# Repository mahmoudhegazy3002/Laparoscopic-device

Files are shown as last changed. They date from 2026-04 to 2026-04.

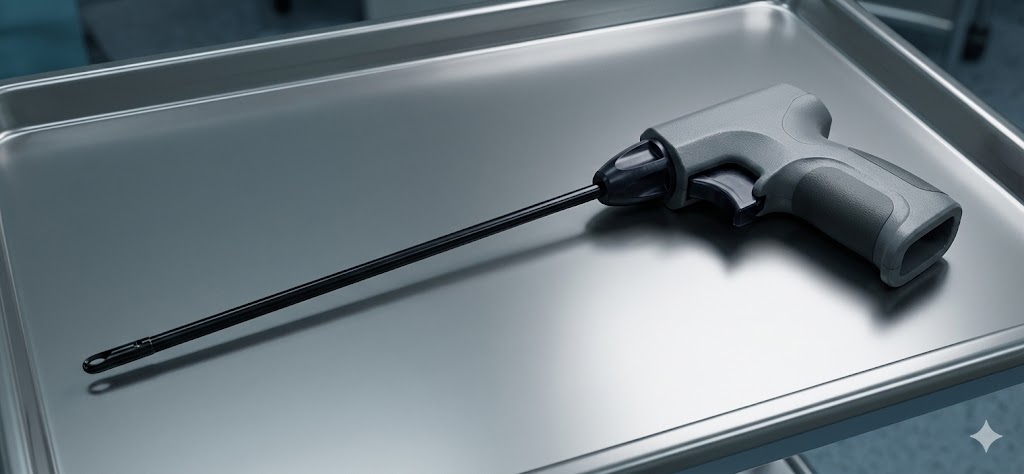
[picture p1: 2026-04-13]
sketches & ideas/unnamed.jpg

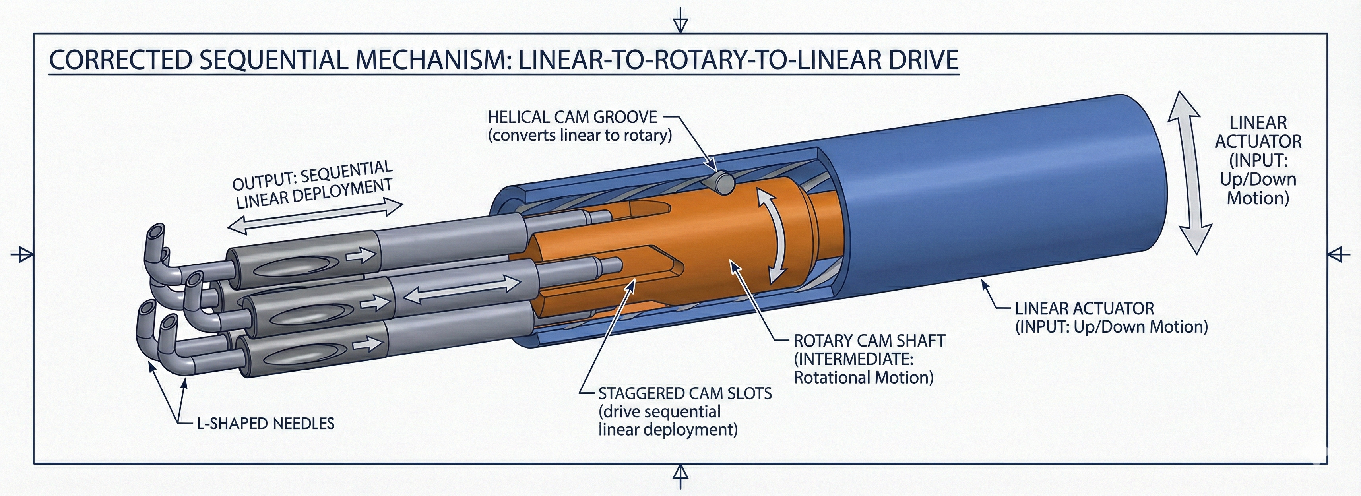
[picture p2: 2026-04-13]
sketches & ideas/img.jpg

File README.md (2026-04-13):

Laparoscopic Device: Kinematics & Force Simulation 🏥⚙️
📌 Project Overview

This project details the mechanical design and dynamic simulation of a specialized laparoscopic surgical tool. The primary engineering objective was to design a reliable mechanical actuation system and accurately model the resistance and force response of the tool's internal mechanisms during operation.
🛠️ Mechanical Design & Mechanisms

The device utilizes precision mechanisms to translate user input into accurate end-effector actuation.

    Native CAD: Designed parametrically in SolidWorks. The repository includes native .SLDPRT and universally accessible .STEP files.

    Cam Barrel Mechanism: Engineered to convert rotary/linear input into specific stroke lengths required for surgical precision.

    Trigger Release Technique: Designed a mechanical release system that ensures consistent actuation and safe reset functionality.

🧮 Dynamic Simulation & Force Modeling

A major component of this project was validating mechanical forces before physical prototyping. The entire kinematic chain was modeled and analyzed using MATLAB & Simscape Multibody.

    Resistance Simulation: Modeled the mechanical resistance of the trigger mechanism to ensure ergonomic operation.

    Mechanical Modeling: The simulation accounts for spring rates, dampening, and the mechanical advantage generated by the cam profile geometry.

📂 Repository Structure

    /cad — Contains SolidWorks feature tree files (.SLDPRT, .SLDASM) and .STEP files.

    /sim — Contains MATLAB/Simscape Multibody files (.slx) and initialization scripts.

    /docs — Contains mechanism diagrams and mathematical derivations for the cam profile.

🚀 How to Explore this Project

    CAD Review: Open the .STEP files in any standard CAD package or use SolidWorks to view the native feature trees.

    Simulation: To run the dynamic simulation, open the .slx file in MATLAB and execute the setup script to load the mechanical parameters.

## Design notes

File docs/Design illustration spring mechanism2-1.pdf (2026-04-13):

## Design and Dynamic Analysis of a Spring-Loaded Trigger Mechanism

Mechanism Engineering Report

March 14, 2026

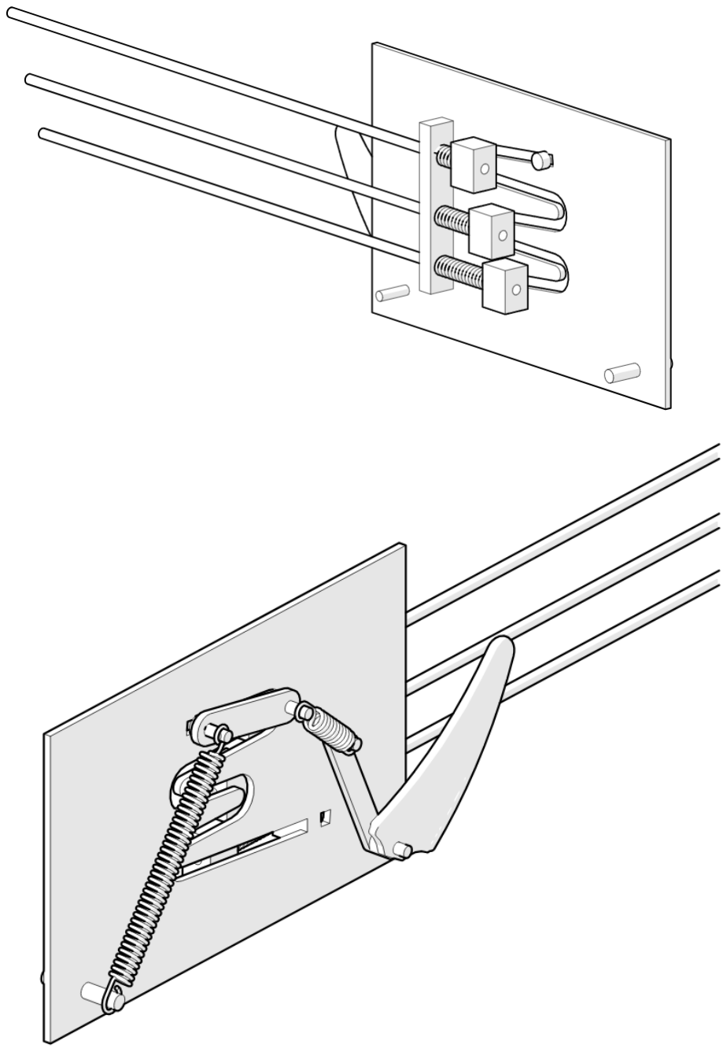
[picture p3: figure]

Abstract
This document details the design, kinematics, and dynamic simulation of a mechanical trigger assembly. The analysis includes a breakdown of the sub-components, an overview of the working principles, and an evaluation of the torque required to actuate the mechanism under a 0.5 kg load based on Simscape Multibody simulations.

## 1 Working Mechanism Illustration

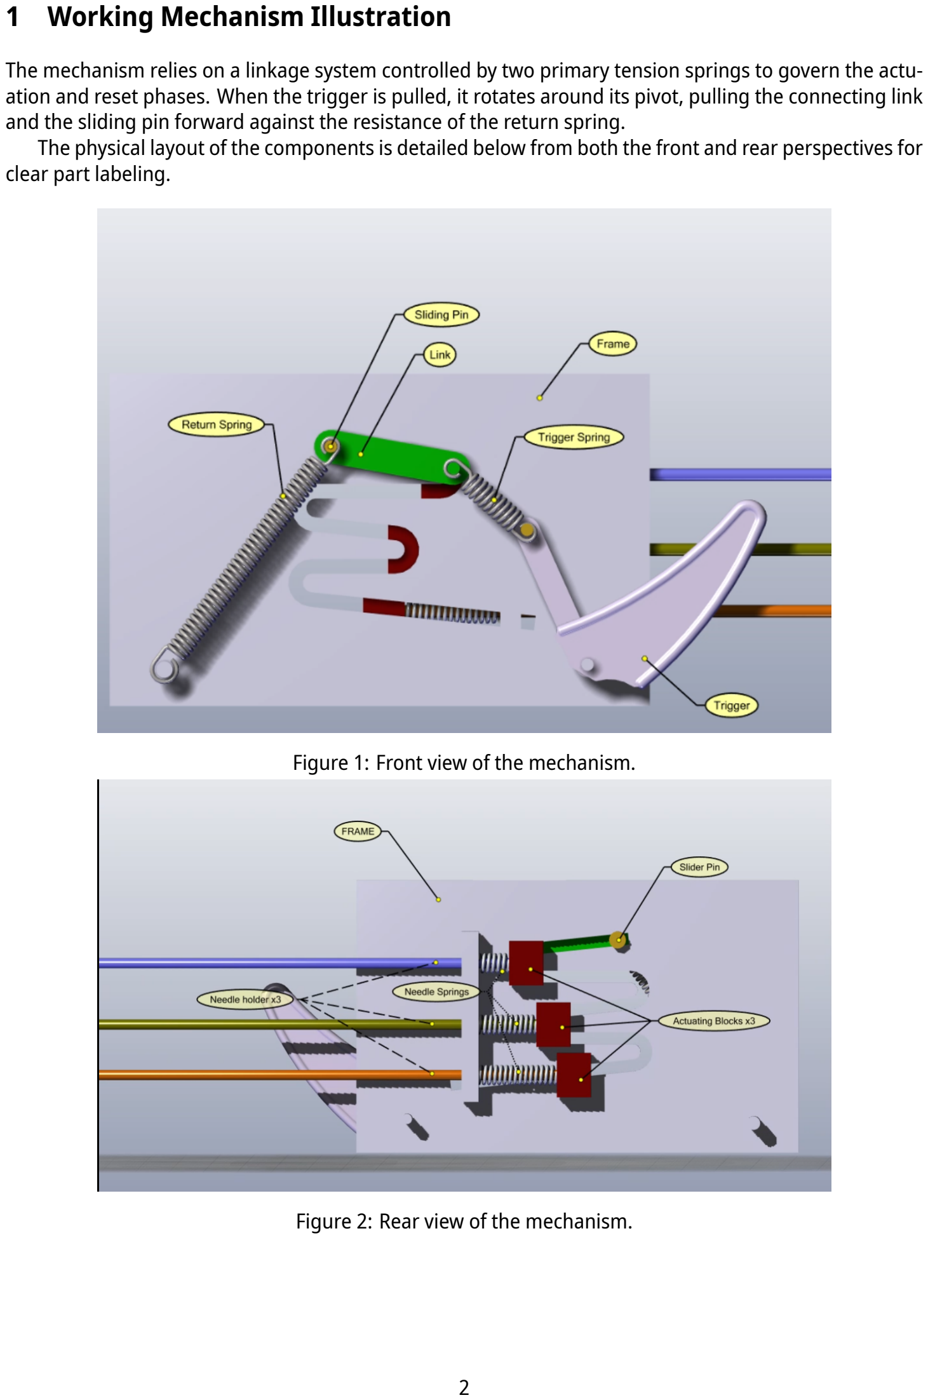
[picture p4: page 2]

The mechanism relies on a linkage system controlled by two primary tension springs to govern the actuation and reset phases. When the trigger is pulled, it rotates around its pivot, pulling the connecting link and the sliding pin forward against the resistance of the return spring.
The physical layout of the components is detailed below from both the front and rear perspectives for clear part labeling.

Figure 1: Front view of the mechanism.

Figure 2: Rear view of the mechanism.

The trigger spring maintains tension between the frame and the trigger to provide a crisp reset, while the heavier return spring is responsible for driving the sliding pin back to its resting state once the sear/trigger is released.

## 2 Parts List and Bill of Materials

The mechanism consists of a simplified kinematic chain with rigid bodies and force elements. The primary components are detailed in Table 1.

Table 1: Primary Components of the Trigger Assembly

Item No. Part Description | Quantity
1 | Frame | 1
2 | Trigger | 1
3 | Link | 1
4 | Sliding Pin (Slider Pin) | 1
5 | Trigger Spring | 1
6 | Return Spring | 1
7 | Needle Holder | 3
8 | Needle Spring | 3
9 | Actuating Block | 3
10 | Pivot Pins | 3

## 3 Operational Phases

The actuation cycle of the mechanism is broken down into six distinct phases, illustrating the progression of the linkages throughout a complete pull and reset cycle.

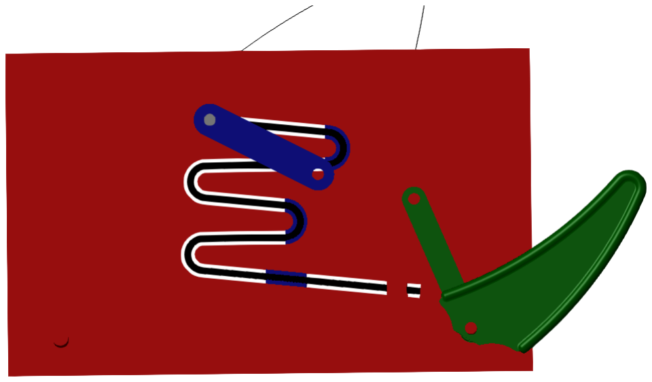
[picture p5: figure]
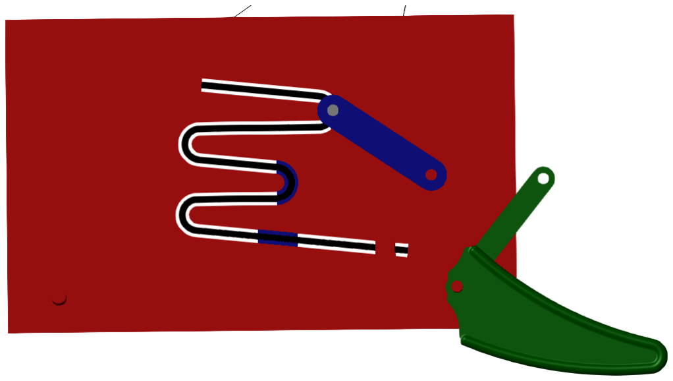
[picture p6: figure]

Figure 3: Phase 1: Initial Resting state. | Figure 4: Phase 2: pull and 1st needle actuated.

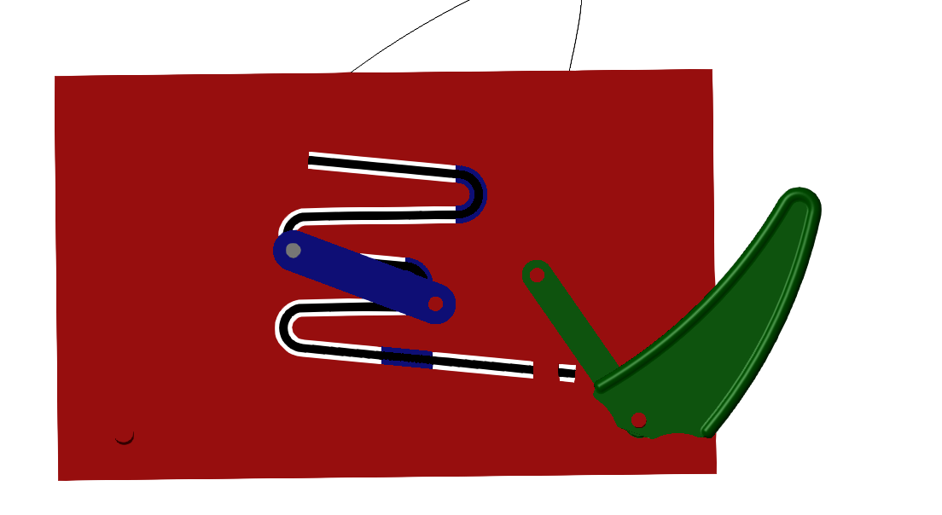
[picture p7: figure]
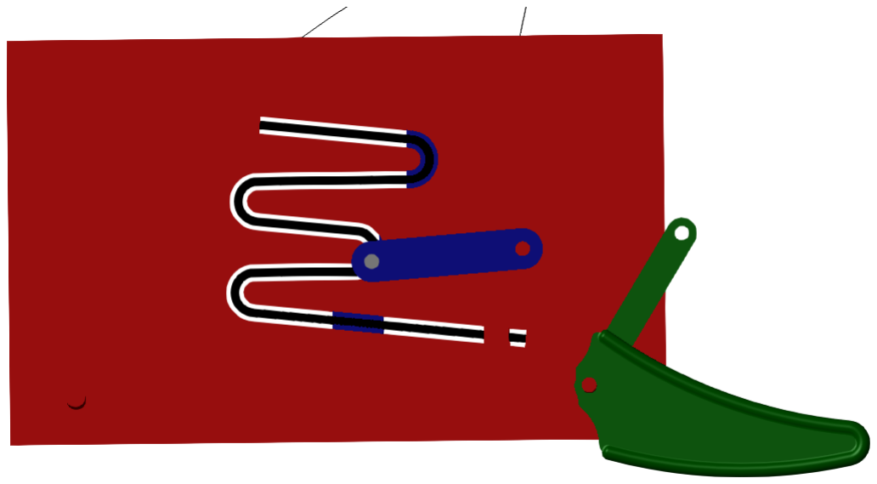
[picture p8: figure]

Figure 5: Phase 3: Release and 2rd resting state. Figure 6: Phase 4: Pull and 2nd needle actuated.

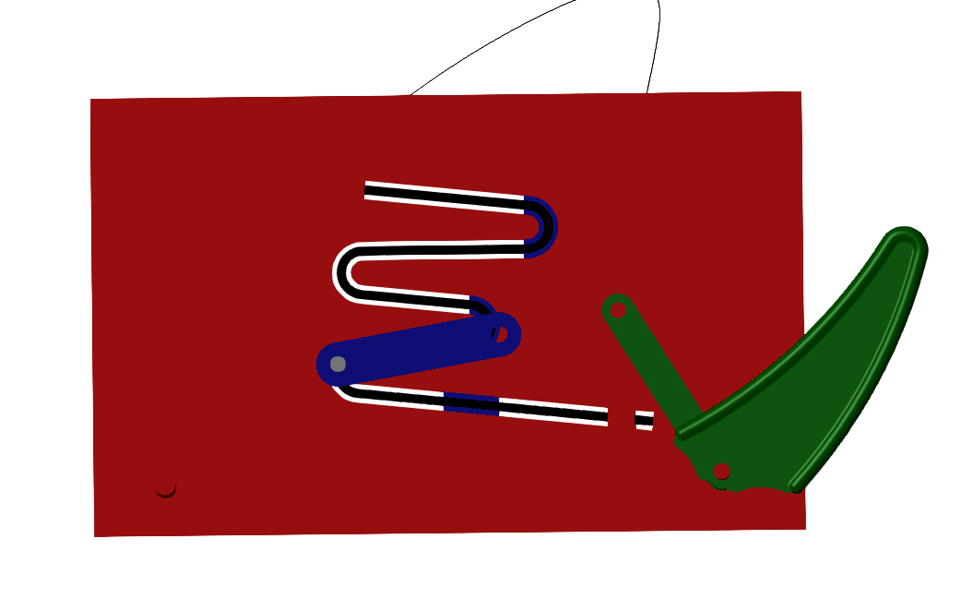
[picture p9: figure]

Figure 7: Phase 5: Release and 3rd resting state.

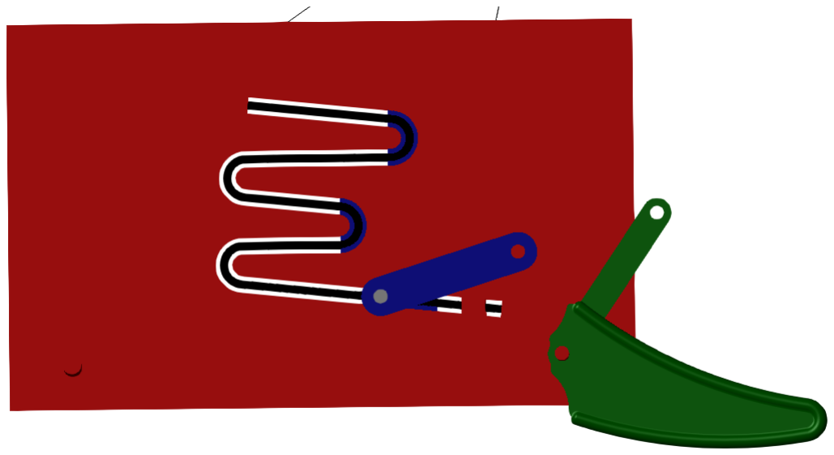
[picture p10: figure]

Figure 8: Phase 6: Pulls 3rd needle actuated

## 4 Dynamic Analysis and Torque Requirements

A rigid-body dynamics simulation was conducted in MATLAB/Simscape to evaluate the holding and actuation torque at the trigger pivot. The design target for the mechanism was a comfortable finger-pull load of approximately 0.5 kg.
Given a mass m = 0.5 kg, the applied force F is calculated as:
F = m · g = 0.5 · 9.81 ≈ 4.9 N | (1)

Assuming a standard trigger moment arm r = 0.03 m, the theoretical required torque τ is approximately 0.15 Nm (150 Nmm).
The dynamic simulation results capture both the kinematic motion and kinetic requirements over multiple actuation cycles, which are broken down in the following sections.

## 5 Trigger Position vs. Time

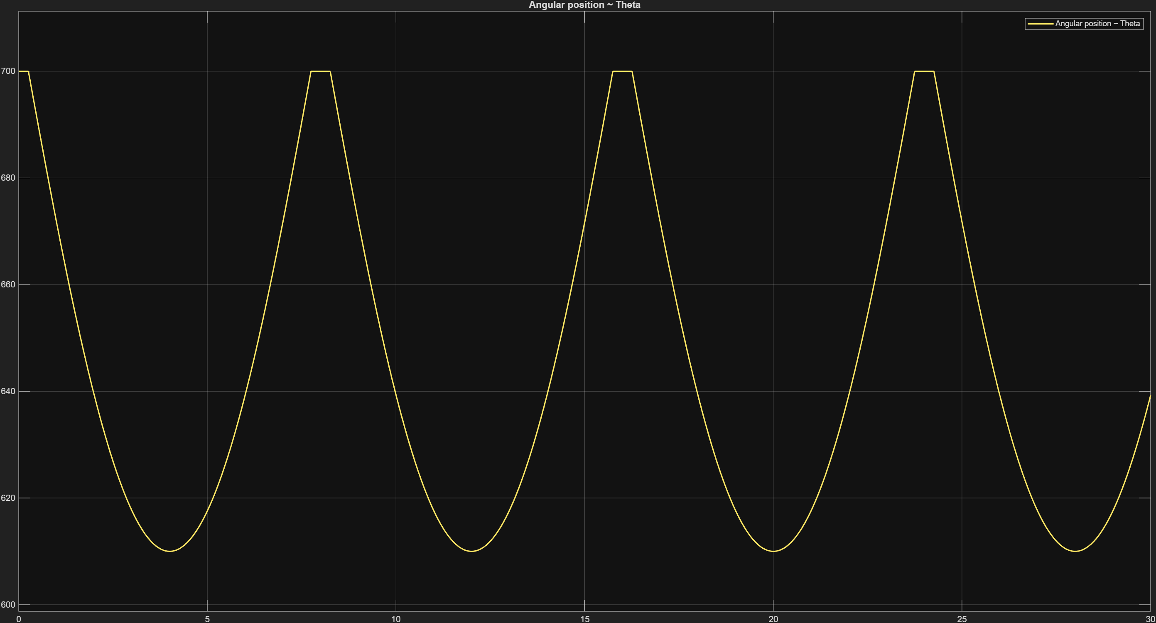
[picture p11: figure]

Figure 9: Simscape simulation output showing the kinematic position of the trigger over time.

## 6 Trigger Torque vs. Time

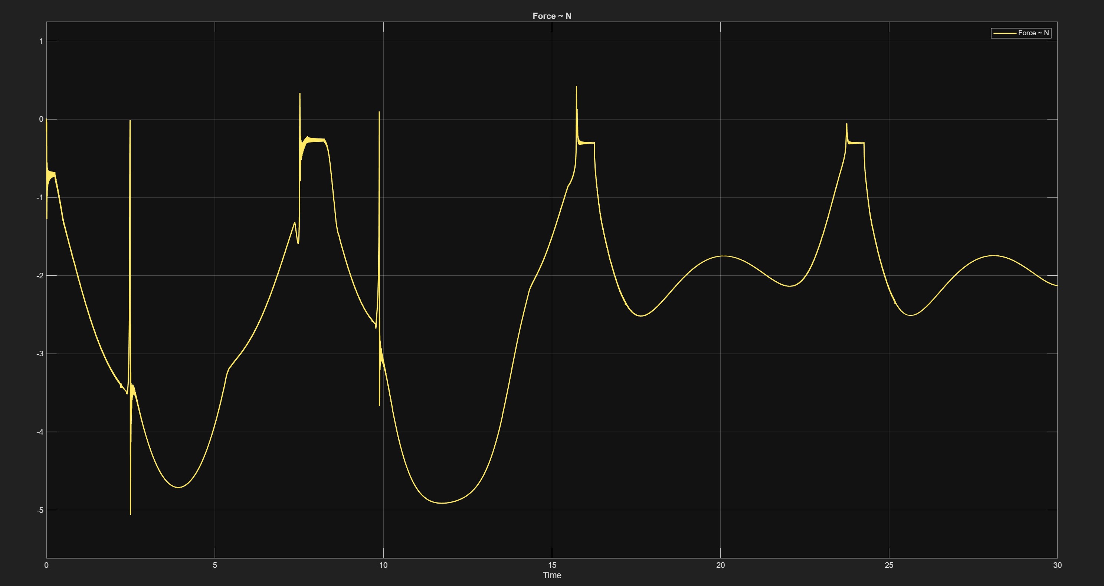
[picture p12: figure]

Figure 10: Simscape simulation output showing the required actuation torque over a multi-cycle test.

The torque graph exhibits transient spikes during the initial pull and reset phases, indicating sudden impacts or hard-stop collisions within the joint limits. Depending on the simulation’s base unit scale (Nm vs Nmm), these spikes (peaking at magnitude 9) suggest either excessive inertia in the CAD model properties or a lack of sufficient damping coefficients in the Revolute Joint configuration.

## 7 Conclusion and Recommendations

This spring-loaded trigger mechanism provides a simple solution that is highly advantageous due to its ease of manufacturing and low overall production cost. While the kinematic linkages function as intended to drive the sliding pin, the system requires optimizing the springs’ stiffness to provide a better, more comfortable trigger feel. Furthermore, the performance of the sliding roller may be affected by the physical path it moves in, requiring careful consideration of tolerances and friction. Moving forward, it is also recommended to mitigate the severe transient torque spikes observed in Figure 10 by adjusting damping coefficients and verifying the torque output scaling in the dynamic simulation.

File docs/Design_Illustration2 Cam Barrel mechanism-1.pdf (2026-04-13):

## Design and Kinematic Analysis of a Cam-Follower Mechanism

Mechanism Engineering Report

March 14, 2026

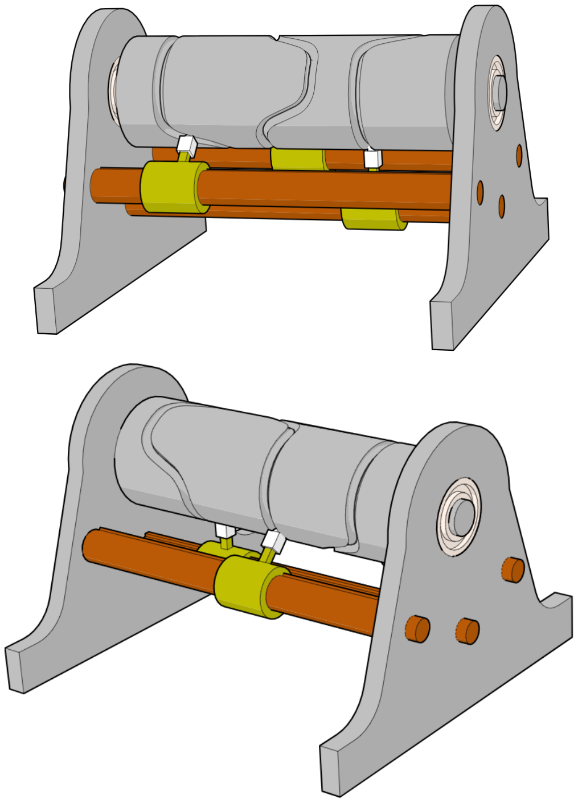
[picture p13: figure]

Abstract
This document details the design and kinematic simulation of a mechanical cam and follower assembly. The analysis includes a breakdown of the sub-components, an overview of the working principles, and an evaluation of the mechanism’s kinematic profile, illustrating the precise and independent actuation of the system’s needles.

## 1 Working Mechanism Illustration

The mechanism relies on a rotating barrel cam to translate continuous rotational motion into precise, linear reciprocating motion at the followers. As the cam barrel rotates, the sweeping cam grooves actively guide the follower pins back and forth along the guiding rods, providing positive control in both directions without the need for a return spring.
The physical layout of the components is detailed below from both the front and rear perspectives for clear part labeling.

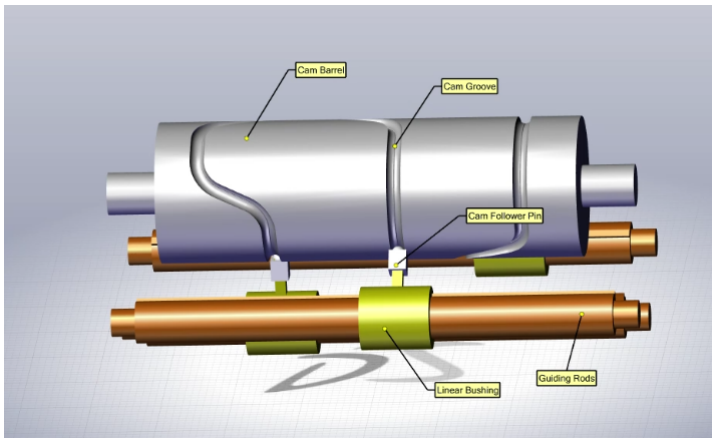
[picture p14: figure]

Figure 1: Front view of the mechanism.

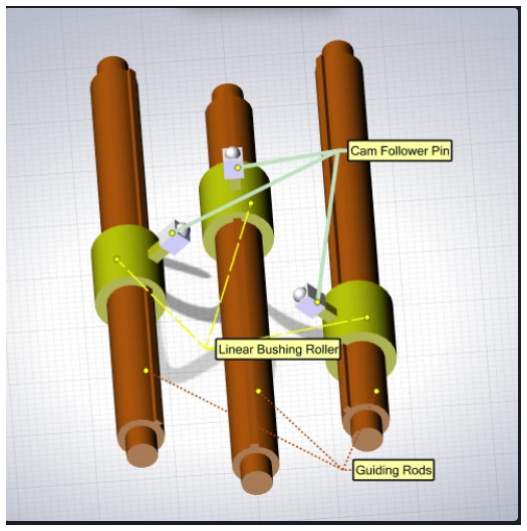
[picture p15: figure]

Figure 2: Rear view of the mechanism.

The grooved barrel design maintains constant contact with the follower pins, ensuring that the mechanism tracks the designated profile accurately. Because this mechanism is designed for deliberate, lowspeed manual actuation rather than continuous high-speed motor driving, a thumbwheel is utilized to rotate the cam barrel. This allows for precise, user-controlled adjustments of the linear mechanisms.

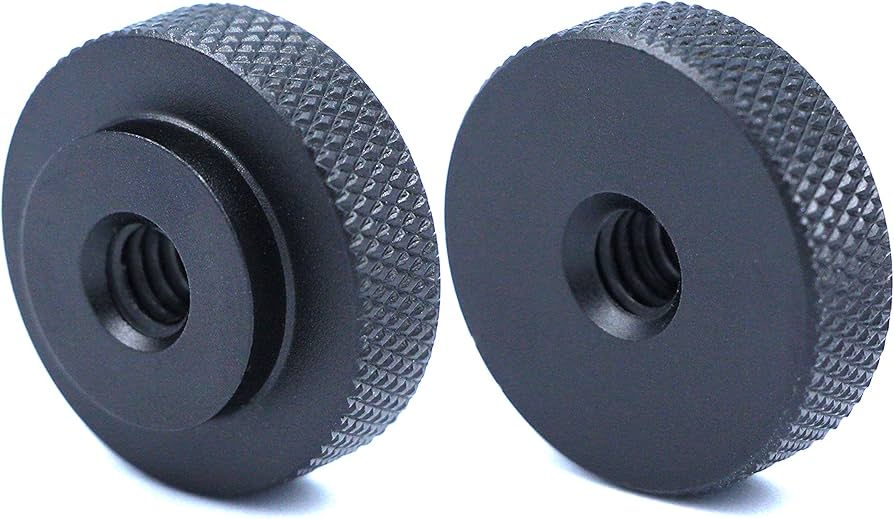
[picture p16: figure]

Figure 3: Detail view of the thumbwheel used for manual actuation of the cam barrel.

## 2 Parts List and Bill of Materials

The mechanism consists of a simplified kinematic chain with rigid bodies and force elements. The primary components are detailed in Table 1.

Table 1: Primary Components of the Cam Assembly

Item No. Part Description | Quantity
1 | Frame / Base | 1
2 | Cam Barrel (with Cam Grooves) | 1
3 | Guiding Rods | 3
4 | Linear Bushing & Cam Follower Pin* | 3
5 | Bearings | 2
6 | Thumbwheel (Manual Actuator) | 1

*Note: The Linear Bushing (Roller) and the Cam Follower Pin will be manufactured as a single integrated component in reality. They were solely separated into two distinct parts within the software environment for the purposes of kinematic modeling and dynamic simulation.

## 3 Operational Phases

The actuation cycle of the mechanism is broken down into distinct phases, illustrating the progression of the follower throughout a complete 360-degree rotation of the cam.

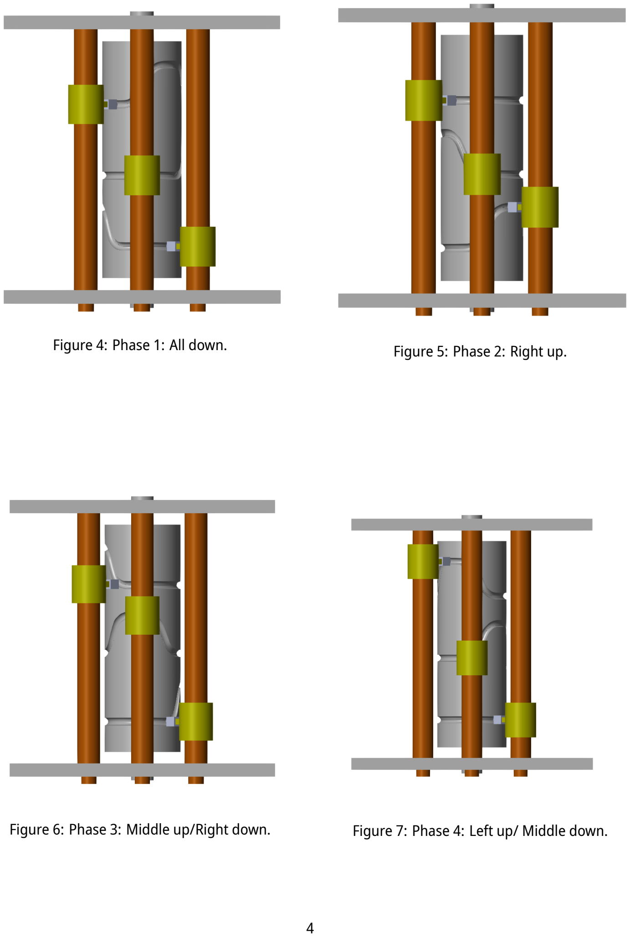
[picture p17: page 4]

Figure 4: Phase 1: All down. | Figure 5: Phase 2: Right up.
Figure 6: Phase 3: Middle up/Right down. | Figure 7: Phase 4: Left up/ Middle down.

## 4 Kinematic Profile

A kinematic simulation was conducted to evaluate the linear motion of the mechanism over time. Rather than focusing on dynamic torque, this analysis validates the precise timing and displacement generated by the cam profile.
The resulting kinematic profile captures the linear position of the assembly during operation. Specifically, the simulation output demonstrates how each needle moves entirely alone with respect to the other two, ensuring that their individual actuation phases do not overlap incorrectly.

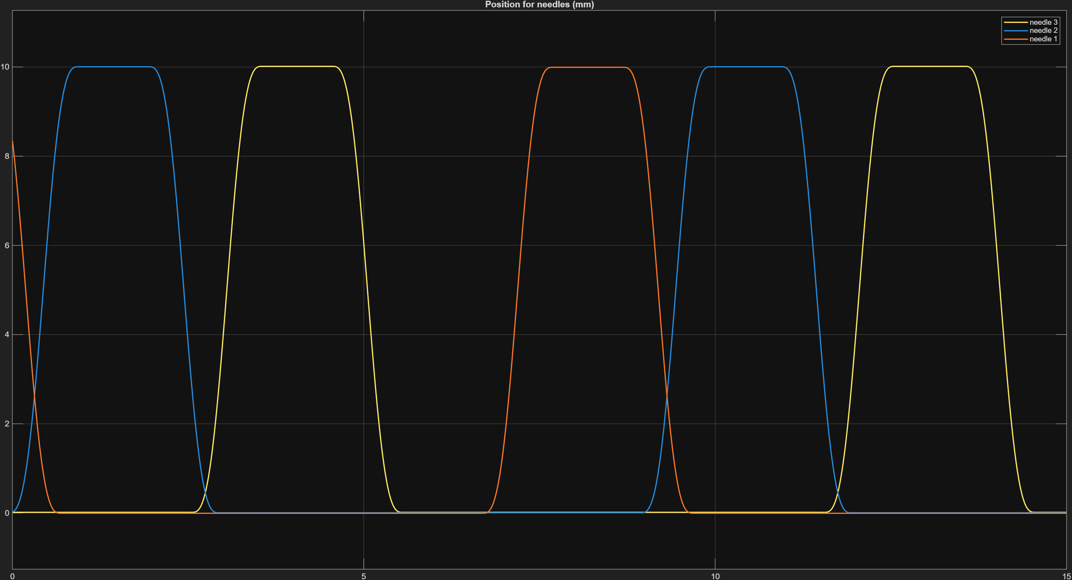
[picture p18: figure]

Figure 8: Kinematic profile output showing the linear position over time, illustrating that each needle actuates independently with respect to the other two.

## 5 Conclusion and Recommendations

This barrel cam-follower mechanism provides a reliable and highly precise method for translating continuous rotary motion into specific, multi-axis linear sequences. The positive-return nature of the cam grooves guarantees accurate tracking and timing without relying on spring tension.
As demonstrated by the kinematic profile, the system effectively manages the timing of multiple actuations, ensuring that each needle moves independently of the others. To optimize this design for manufacturing, it is critical to ensure high-precision CNC machining of the cam grooves to minimize backlash and maintain this exact timing. Additionally, proper tolerancing and lubrication between the guiding rods and linear bushings will be essential to reduce sliding friction and extend the overall lifespan of the mechanism.
For future design iterations and optimization, another configuration could be utilized to reduce the overall length of the cam barrel. By designing the left and right cam followers to track along the same groove path, the total number of required grooves is decreased, allowing for a more compact barrel length. Furthermore, the system’s capacity could be expanded to accommodate an increased number of needles by increasing the cam barrel diameter. However, this modification must be carefully considered, as a larger diameter may directly affect the overall size and form factor constraints of the laparoscopic device.

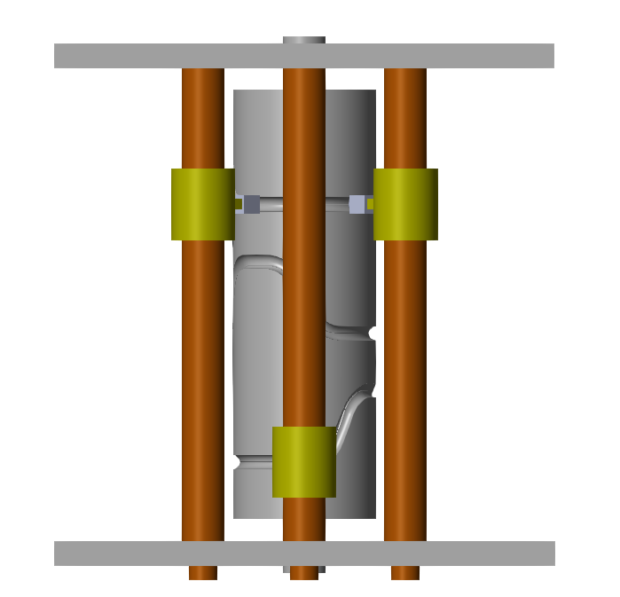
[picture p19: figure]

Figure 9: Proposed alternative configuration utilizing a shared cam groove to reduce overall barrel length.

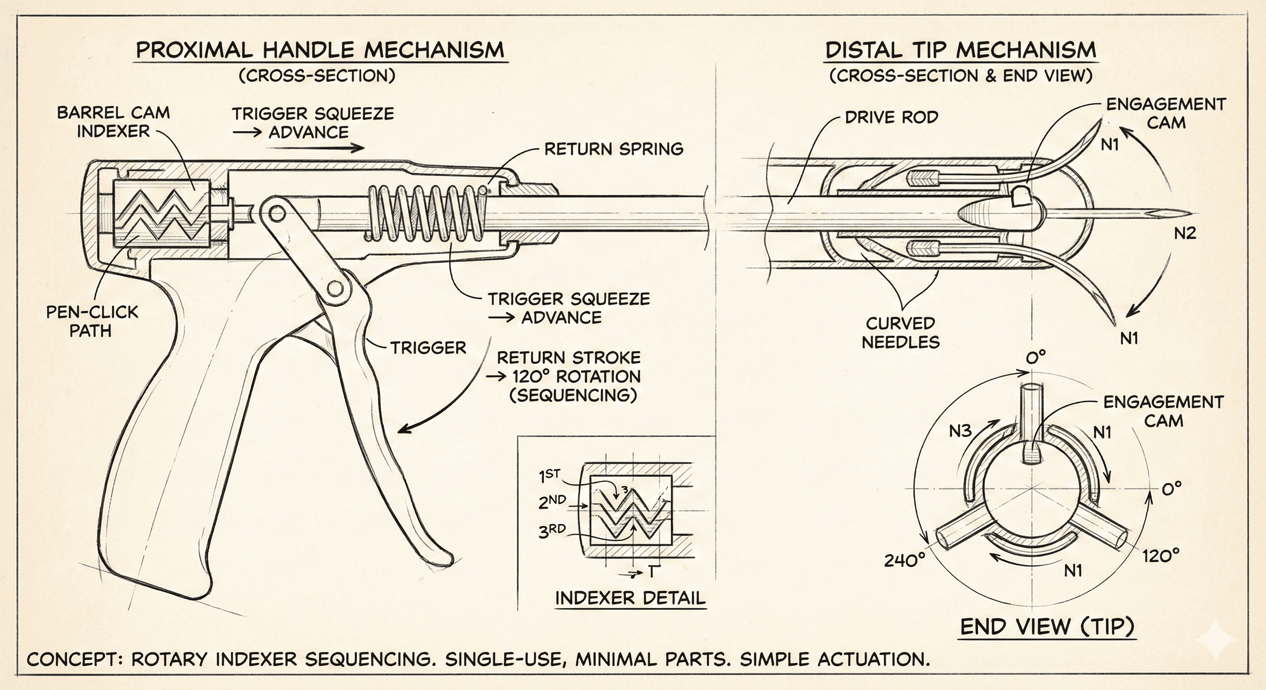
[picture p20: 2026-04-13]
sketches & ideas/image+4.png

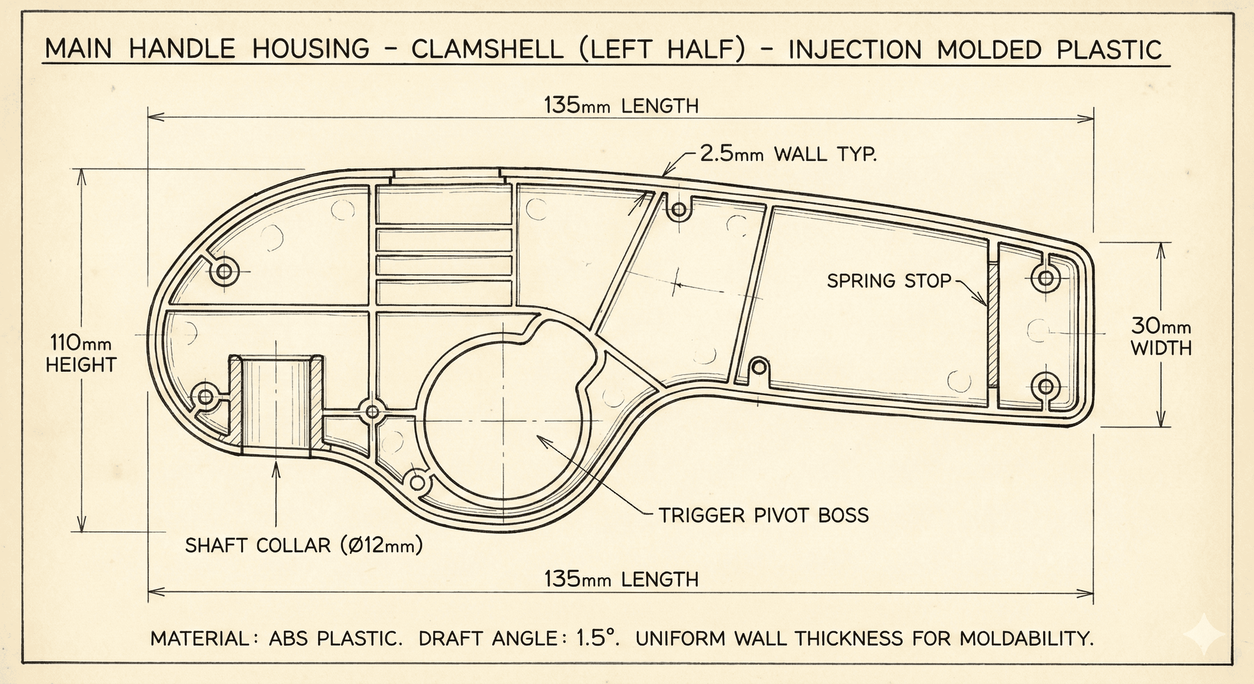
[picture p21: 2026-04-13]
sketches & ideas/image+3.png

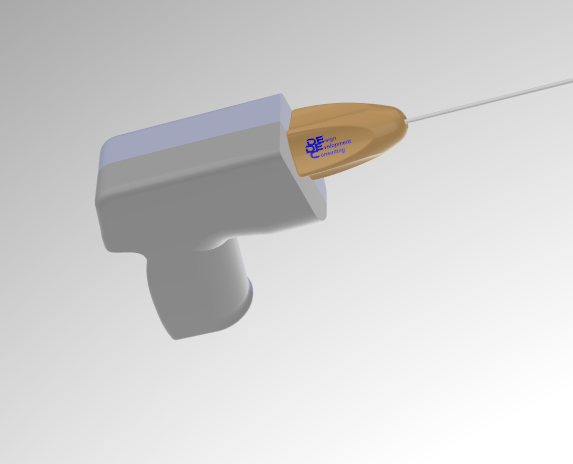
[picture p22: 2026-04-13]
sketches & ideas/gun2.png

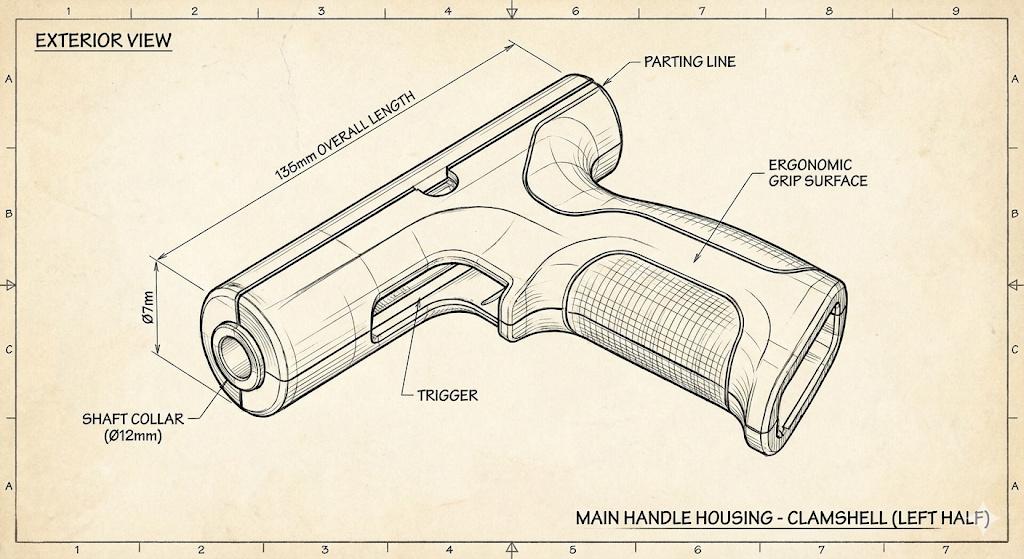
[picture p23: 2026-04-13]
sketches & ideas/image+2++objective+.jpg

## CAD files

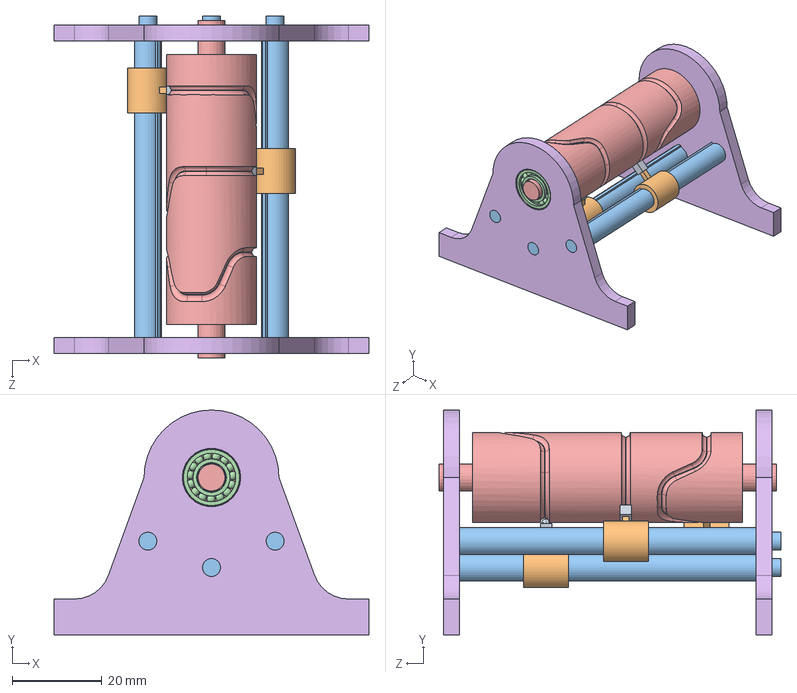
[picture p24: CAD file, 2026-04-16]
Mechanism 2/cad/3 cam sequential assembly.SLDASM
70.0 x 50.0 x 76.0 mm
Cam Mount x 2
cam
radial ball bearing_68_skf x 2
Linear roller fixation x 3
Linear roller x 3
Linear roller joiny x 3

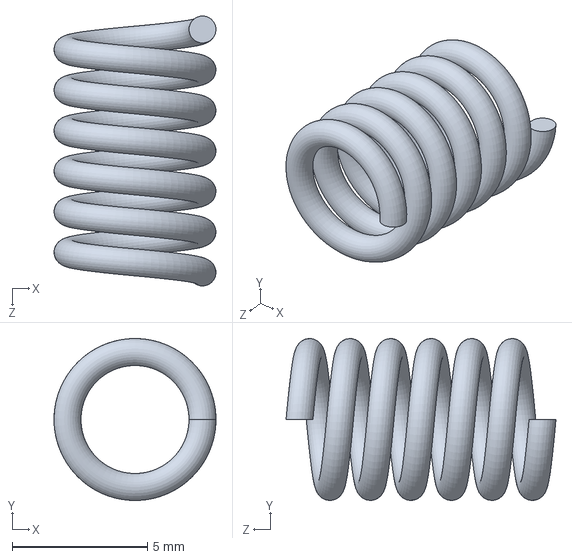
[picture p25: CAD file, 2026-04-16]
Mechanism 1/cad/Spring1.SLDPRT
6.00 x 6.00 x 10.00 mm

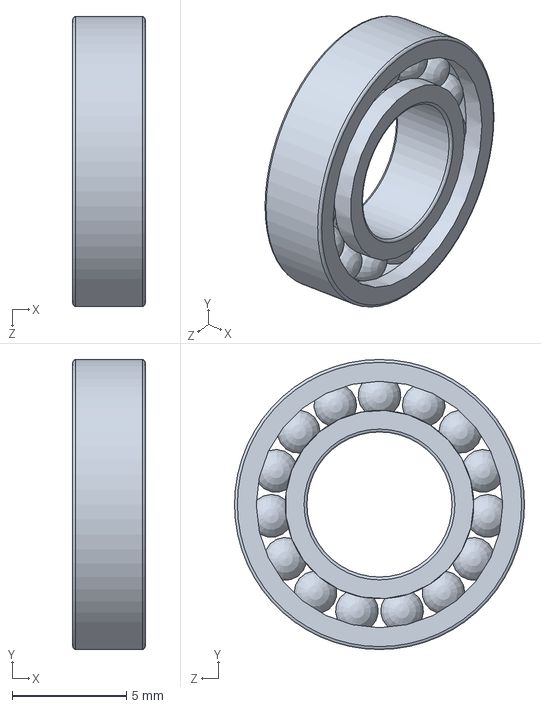
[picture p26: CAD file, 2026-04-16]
Mechanism 2/cad/ball bearings/radial ball bearing_68_skf.sldprt
3.17 x 12.7 x 12.7 mm

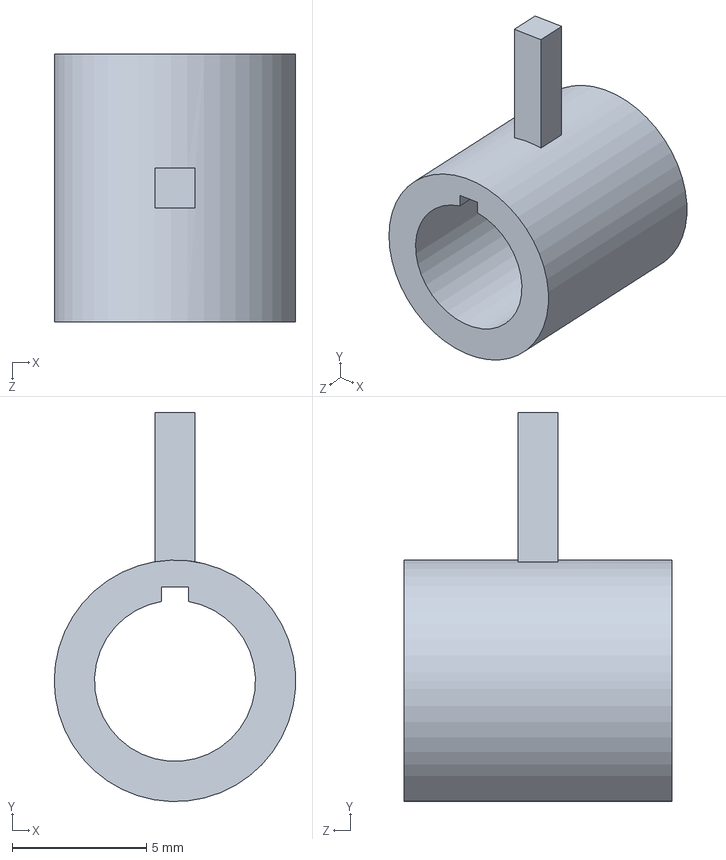
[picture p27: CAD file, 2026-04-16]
Mechanism 2/cad/Linear roller.SLDPRT
9.00 x 14.5 x 10.0 mm

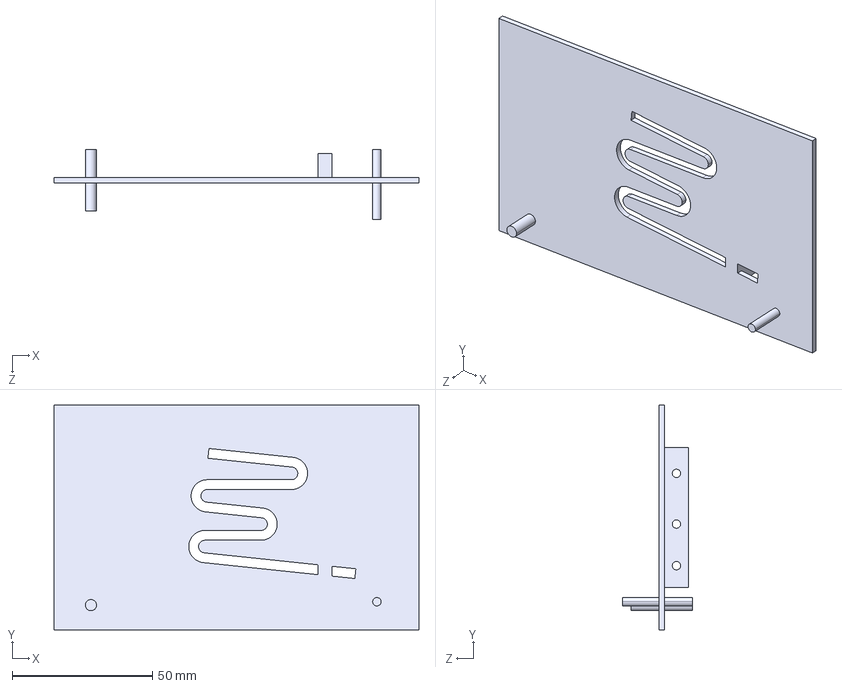
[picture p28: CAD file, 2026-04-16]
Mechanism 2/src/simple3.STEP
130.0 x 80.0 x 25.0 mm

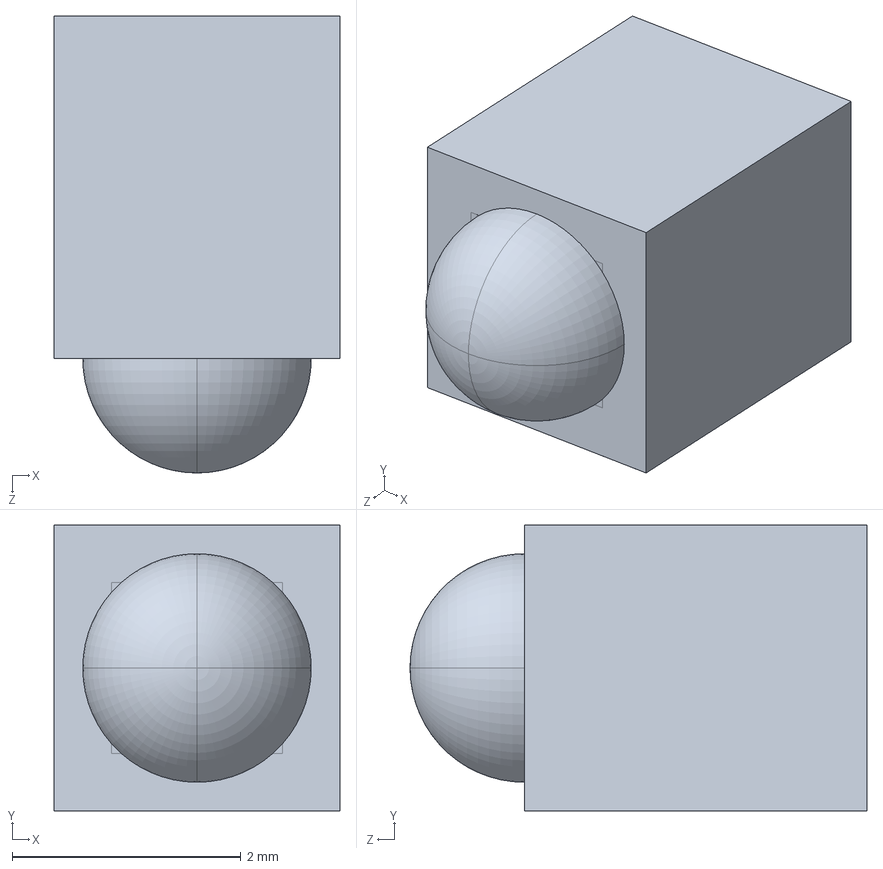
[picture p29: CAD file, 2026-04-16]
Mechanism 2/cad/Linear roller joiny.SLDPRT
2.50 x 2.50 x 4.00 mm

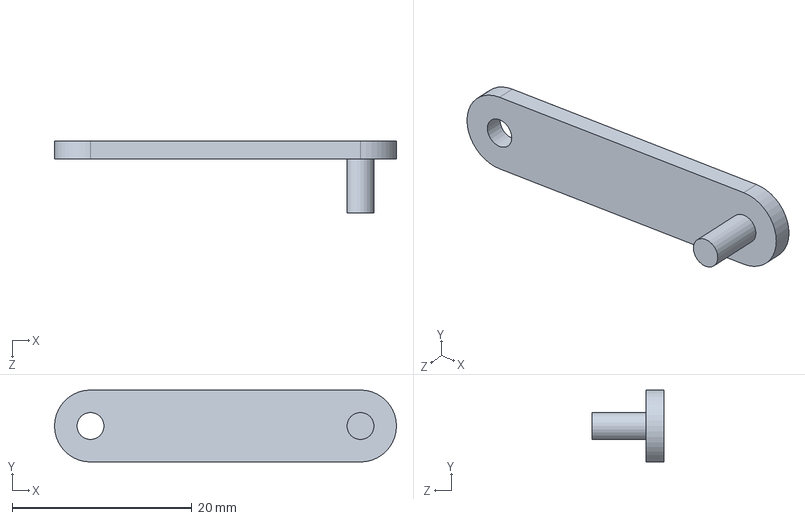
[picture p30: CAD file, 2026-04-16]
Mechanism 1/cad/link pin.SLDPRT
38.0 x 8.00 x 8.00 mm

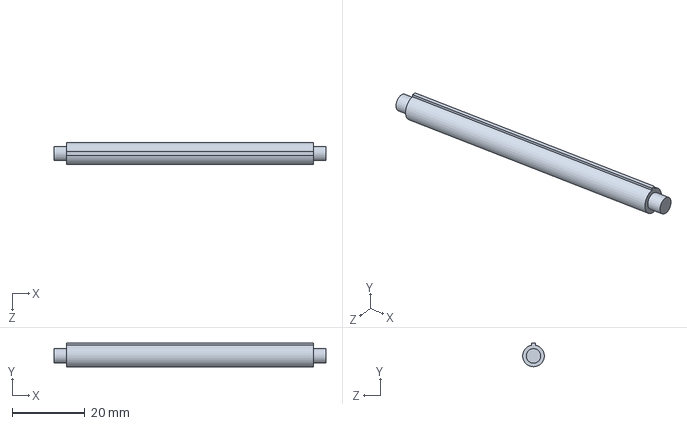
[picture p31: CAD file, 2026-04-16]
Mechanism 2/cad/Linear roller fixation.SLDPRT
75.0 x 6.50 x 6.00 mm

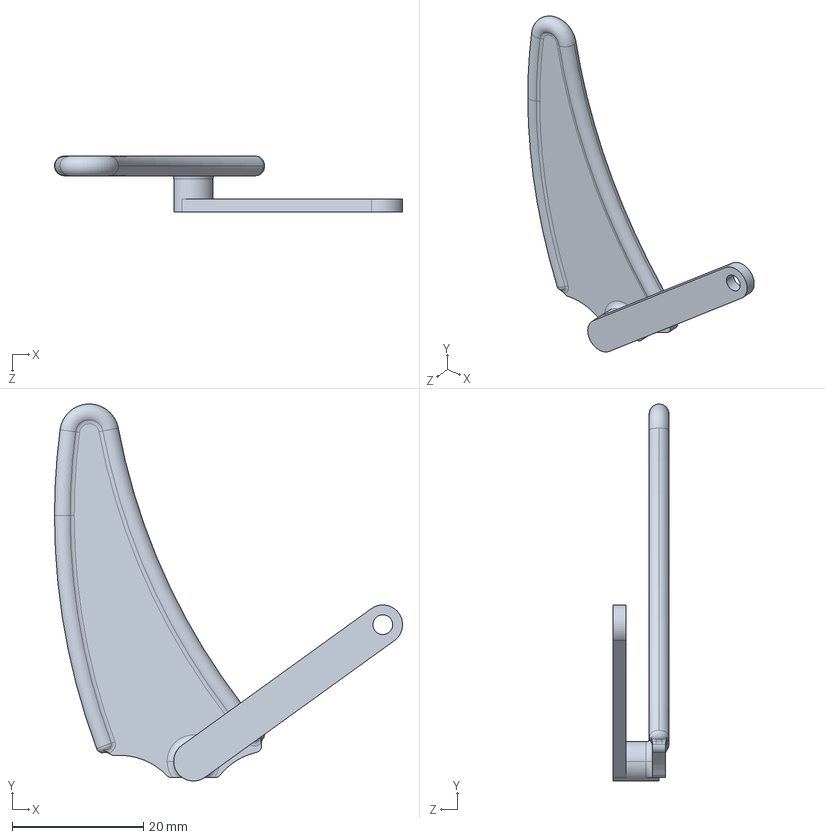
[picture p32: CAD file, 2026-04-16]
Mechanism 2/src/hand trigger_Default_sldprt.STEP
53.0 x 57.4 x 8.50 mm

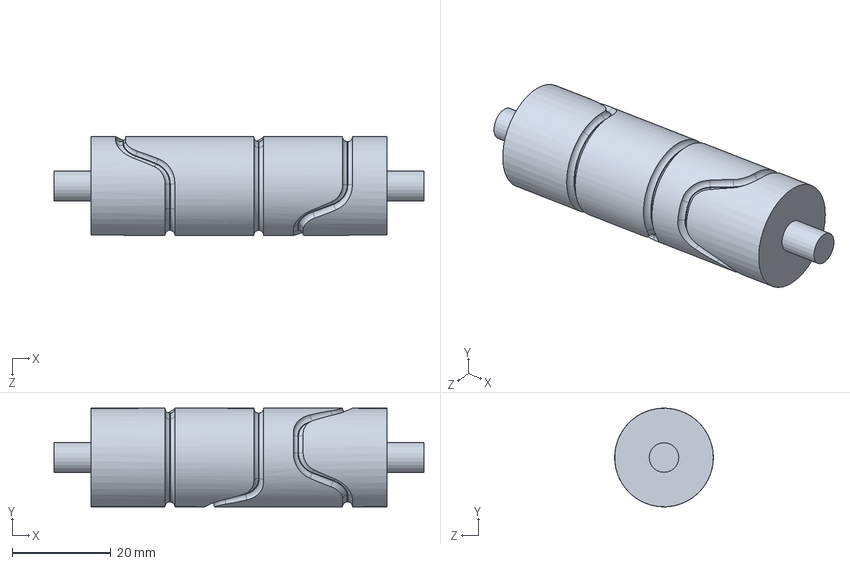
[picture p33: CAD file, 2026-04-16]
Mechanism 2/cad/cam.SLDPRT
75.0 x 20.0 x 20.0 mm

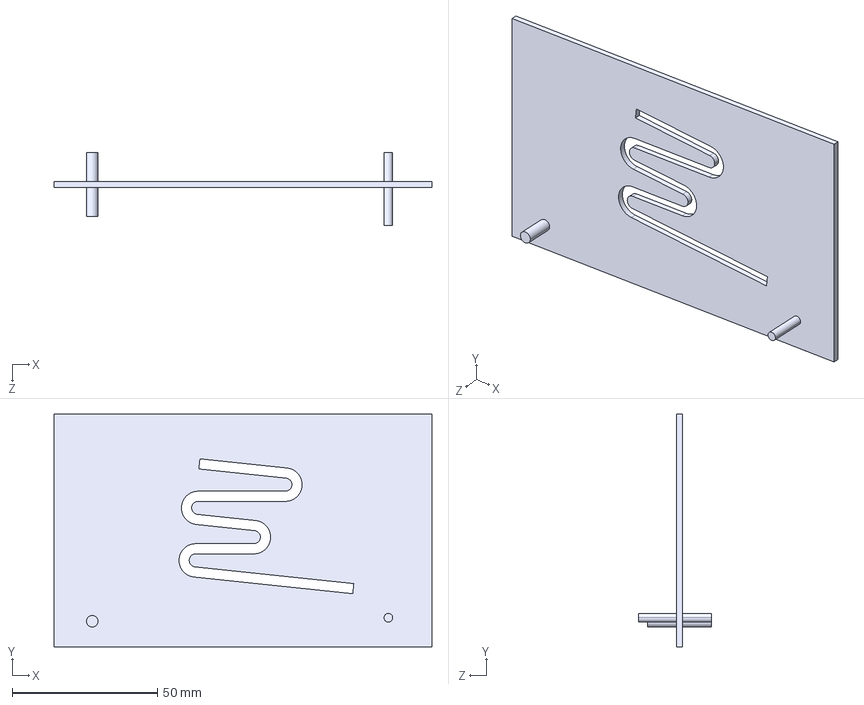
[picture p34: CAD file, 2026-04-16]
Mechanism 2/src/simple.STEP
130.0 x 80.0 x 25.0 mm

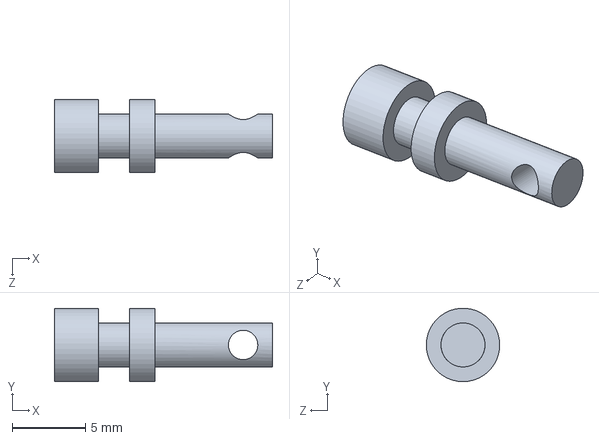
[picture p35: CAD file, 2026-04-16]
Mechanism 1/cad/pin pather.SLDPRT
14.8 x 4.99 x 5.00 mm

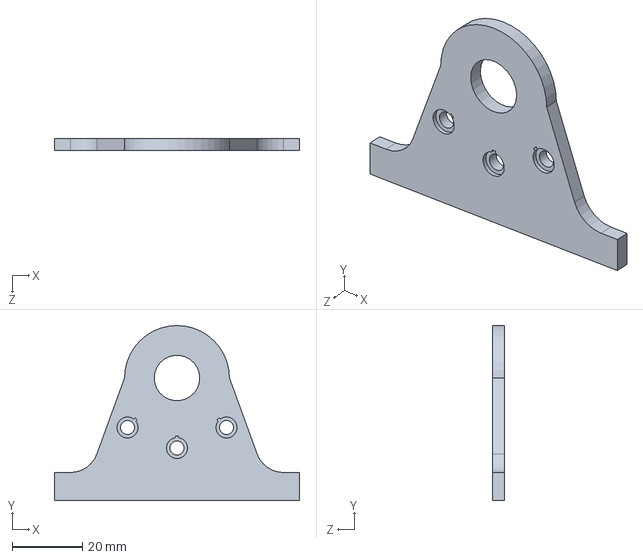
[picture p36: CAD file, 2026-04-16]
Mechanism 2/cad/Cam Mount.SLDPRT
70.0 x 50.0 x 3.50 mm

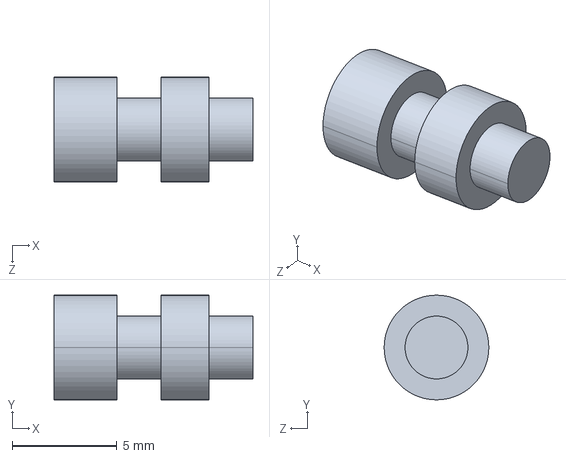
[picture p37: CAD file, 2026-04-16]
Mechanism 2/src/pin pather_Default_sldprt.STEP
9.50 x 5.00 x 5.00 mm

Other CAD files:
Mechanism 1/cad/3 needle mechanism.SLDASM
Mechanism 1/cad/simple.SLDPRT
Mechanism 1/cad/Spring Preload.SLDPRT
Mechanism 1/cad/Needle holder.SLDPRT
Mechanism 1/cad/Spring trigger.SLDPRT
Mechanism 1/cad/Spring2.SLDPRT
Mechanism 1/cad/Spring3.SLDPRT
Mechanism 1/cad/hand trigger.SLDPRT
Mechanism 1/cad/needle housing.SLDPRT
Mechanism 1/cad/pin trigger.SLDPRT
Mechanism 2/src/link pin_Default_sldprt.STEP
Mechanism 2/src/simple2.STEP
Mechanism 2/src/simple_Default_sldprt.STEP
Mechanism 2/src/springpart1 model_Default_sldprt.STEP
Mechanism 2/src/springpart2 model_Default_sldprt.STEP
